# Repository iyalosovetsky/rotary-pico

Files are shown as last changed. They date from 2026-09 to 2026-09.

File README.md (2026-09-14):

*[Українська версія](README.uk.md)*

# rotary-pico

## 1. Description

Control firmware for a DIY turntable rig for a Creality Raptor-style 3D scanner, built on a **BTT SKR Pico** board (RP2040, MicroPython).

> See also [this grblHAL RP2040 fork](https://github.com/iyalosovetsky/RP2040_pico2w) — the same turntable/servo rig driven on top of grblHAL (M101 servo command, M102/M103/M104 table rotation) instead of standalone MicroPython.
>
> [Demo video](https://www.youtube.com/watch?v=oVeflQN5IRw) of the rig in action.

- **X axis** — rotates the table (continuous rotation, speed control), plus a one-shot relative rotation to a given angle.
- **Y/Z axes** — cyclic motion between a lower and upper limit, no physical endstops: `HOME` drives the axis until the TMC2209's StallGuard (sensorless homing) detects a genuine stall, then sets `MIN`/`MAX` to that position — a one-shot calibration, not something re-checked on every bounce. Also support a one-shot relative move to a given distance in millimeters, via a configurable lead screw pitch.
- **ST3215 servo (A)** — tilts the scanner head (cyclic motion between a minimum and maximum angle), plus a one-shot relative move to a given angle using the servo's own position feedback.

X/Y/Z track their current position (an open-loop step count, since none of them has a position sensor) and persist it so it survives a reboot; A doesn't need this since the servo always reports its own true position. `STATUS` shows every axis's position in physical units (mm/degrees).

All axes run concurrently and independently of each other (cooperative multitasking via `uasyncio`), controlled through G-code-like console commands.

The project was inspired by the [Creality Raptor Turntable](https://www.youtube.com/watch?v=kjL7HI78B2U&t=881s) video — `table_models/` contains the turntable models from the same author.

### Project files

| File / folder | Purpose |
|---|---|
| `tmc2209.py` | TMC2209 driver over UART (shared bus, MS1/MS2 addressing) |
| `st3215.py` | ST3215 servo driver (Feetech SMS/STS protocol) |
| `scanner_rig.py` | Orchestrator: async X/Y/Z/servo tasks + console command parser |
| `main.py` | Simple single-motor bench test (bring-up/diagnostics) |
| `test_y_motor.py` | Bench sweep: every microstep setting x three speeds, for characterizing real step rate vs. requested |
| `freecad/` | Own FreeCAD models (stepper motor, servo mount) |
| `table_models/` | Turntable models (STEP) from the inspiring video's author |

### Documentation

- [TMC2209_REGISTERS.md](TMC2209_REGISTERS.md) - every TMC2209 register this codebase uses, bit layouts, and a link to the datasheet
- [ST3215_REGISTERS.md](ST3215_REGISTERS.md) - every ST3215 register this codebase uses, units/scaling, and links to the datasheet
- [PINOUT.md](PINOUT.md) - BTT SKR Pico pin/header reference for this rig's wiring
- [TROUBLESHOOTING.md](TROUBLESHOOTING.md) - debugging log: bugs found, dead ends ruled out, current open issues

## 2. Command reference

Commands are sent one per line over the console (REPL). `MIN`/`MAX`/`SPEED`/`SGTHRS`/`LEAD`/`MICROSTEPS`/`CURRENT` with no value (e.g. `Y MIN`, not `Y MIN 0`) print that field's current value instead of setting it.

| Command | Description |
|---|---|
| `START [minutes]` | Start every axis at once (using whatever they're each already configured with), auto-stop after `minutes` (default 5) |
| `STOP` | Stop every axis immediately |
| `SLEEP` | Stop everything, disable the X/Y/Z drivers, release servo torque (see below) |
| `WAKE` | Undo `SLEEP` by hand (see below) |
| `X SPEED <steps_per_sec>` | Table rotation speed (sign sets direction, 0 = stopped) |
| `X START [CW\|CCW]` | Start table rotation - direction optional, defaults to CW (or last-used) |
| `X STOP` | Stop table rotation |
| `X MIN <deg>` | Default 0 - only used by `MOVE MIN`/`MID` (see below), not a limit on plain numeric `MOVE` |
| `X MAX <deg>` | Default 180 - only used by `MOVE MAX`/`MID` (see below), not a limit on plain numeric `MOVE` |
| `X MOVE <deg\|MIN\|MAX\|MID>` | A number is an unclamped signed relative rotation (multi-revolution moves like `720` are fine) - axis must be stopped first. `MIN`/`MAX`/`MID` go straight to that angle instead (see below) |
| `X ZERO` | Make the current position 0 (see below) |
| `X MICROSTEPS <n>` | Driver microstep resolution: one of 256/128/64/32/16/8/4/2/1 (see below) |
| `X CURRENT <mA>` | Run current for this axis's driver (hold current is auto-derived as half) |
| `X TMC` | TMC2209 driver health: faults, live current, microsteps, mode (see below) |
| `Y MIN <mm>` | Lower limit of carriage travel, in millimeters (via `LEAD`) - default 0 |
| `Y MAX <mm>` | Upper limit of carriage travel, in millimeters (via `LEAD`) - default 4 |
| `Y SPEED <steps_per_sec>` | Carriage speed |
| `Y SGTHRS <0-255>` | StallGuard sensorless-homing threshold (see below) - higher trips more easily |
| `Y HOME [DEC\|INC] [speed]` | One-shot calibration: home toward a StallGuard stall (see below) |
| `Y LEAD <mm>` | Lead screw pitch (mm per screw revolution) - used to convert `MOVE`'s millimeters to steps |
| `Y MOVE <mm\|MIN\|MAX\|MID>` | One-shot move: a signed relative distance in mm (clamped to `MIN`/`MAX`), or straight to `MIN`/`MAX`/the midpoint - axis must be stopped first |
| `Y ZERO` | Make the current position 0 (see below) |
| `Y MICROSTEPS <n>` | Driver microstep resolution: one of 256/128/64/32/16/8/4/2/1 (see below) |
| `Y CURRENT <mA>` | Run current for this axis's driver (hold current is auto-derived as half) |
| `Y TMC` | TMC2209 driver health: faults, live current, microsteps, mode (see below) |
| `Y START` | Start cyclic motion between `MIN` and `MAX` |
| `Y STOP` | Stop the carriage |
| `Z MIN <mm>` | Lower limit of Z travel, in millimeters (via `LEAD`) - default 0 |
| `Z MAX <mm>` | Upper limit of Z travel, in millimeters (via `LEAD`) - default 4 |
| `Z SPEED <steps_per_sec>` | Z axis speed |
| `Z SGTHRS <0-255>` | StallGuard sensorless-homing threshold (see below) - higher trips more easily |
| `Z HOME [DEC\|INC] [speed]` | One-shot calibration: home toward a StallGuard stall (see below) |
| `Z LEAD <mm>` | Lead screw pitch (mm per screw revolution) - used to convert `MOVE`'s millimeters to steps |
| `Z MOVE <mm\|MIN\|MAX\|MID>` | One-shot move: a signed relative distance in mm (clamped to `MIN`/`MAX`), or straight to `MIN`/`MAX`/the midpoint - axis must be stopped first |
| `Z ZERO` | Make the current position 0 (see below) |
| `Z MICROSTEPS <n>` | Driver microstep resolution: one of 256/128/64/32/16/8/4/2/1 (see below) |
| `Z CURRENT <mA>` | Run current for this axis's driver (hold current is auto-derived as half) |
| `Z TMC` | TMC2209 driver health: faults, live current, microsteps, mode (see below) |
| `Z START` | Start cyclic motion between `MIN` and `MAX` |
| `Z STOP` | Stop the Z axis |
| `A MIN <deg>` | Minimum scanner tilt angle (degrees) |
| `A MAX <deg>` | Maximum scanner tilt angle (degrees) |
| `A SPEED <raw_units>` | Servo speed (raw register units, tune empirically) |
| `A MOVE <deg\|MIN\|MAX\|MID>` | One-shot move: a signed relative angle in degrees (clamped to `MIN`/`MAX`), or straight to `MIN`/`MAX`/the midpoint - axis must be stopped first |
| `A TMC` | Servo health: voltage, temperature, load, current, error flags (see below) |
| `A START` | Start cyclic tilt between `MIN` and `MAX` |
| `A STOP` | Stop the servo |
| `STATUS` | Current position and config of all four axes (X/Y/Z in steps + degrees/mm, A read live from the servo) |
| `HELP` | Command help |

Example session:

```
Y HOME
Z HOME
X SPEED 200
X START
Y SPEED 400
Y START
Z SPEED 400
Z START
A MIN 30
A MAX 150
A SPEED 300
A START
STATUS
```

Or, for one-shot positioning instead of continuous cycling:

```
Y HOME
Y LEAD 4
Y MOVE 25.5
X MOVE 90
A MOVE -15
STATUS
```

Or straight to a limit instead of a relative distance:

```
Y MOVE MIN
Y MOVE MAX
Y MOVE MID
A MOVE MID
```

### Y/Z sensorless homing (StallGuard)

Y and Z have no physical endstop switches. Instead, `HOME` deliberately drives the axis toward one end (`DEC` = decreasing position, `INC` = increasing; Y defaults to `DEC`, Z to `INC`) while polling the TMC2209's StallGuard result (`SG_RESULT`) over UART - it drops as motor load rises, so driving into a real mechanical stop reads as a stall. Once that happens, `MIN` (for a `DEC` stall) or `MAX` (for an `INC` stall) is set to the position it stalled at.

This is a one-shot calibration - run `HOME` once before the first `START`, the way Klipper/Voron-style sensorless homing works. Ordinary bouncing afterward does **not** re-check StallGuard on every move: it runs the quieter stealthChop mode at full current, under which the StallGuard signal isn't reliable enough to act on. `HOME` switches to spreadCycle and a reduced current just for the homing move, then restores normal settings afterward.

`SGTHRS` has no universal default - it's specific to your motor, current, speed and mechanics, and must be tuned by hand:

1. Set a low `SGTHRS` (e.g. 1-3) and run `HOME`.
2. If it stops almost immediately (before reaching the real limit), lower `SGTHRS` further isn't the fix - it likely means the axis hasn't ramped up to a speed where StallGuard's reading is meaningful yet; check `HOME`'s speed argument.
3. If `HOME` fails with "StallGuard never tripped", raise `SGTHRS` until it reliably trips right at the real mechanical limit, not before.

### Zeroing the origin (ZERO)

`X`/`Y`/`Z ZERO` does the same zeroing `HOME` does (current position becomes 0, `MIN`/`MAX` shift by the same offset so they keep meaning the same real distance from the new origin) but instantly, wherever the axis currently is - no motion, no StallGuard involved. Use it to redefine the origin by hand instead of (or in addition to) a StallGuard-based `HOME`. X has no `HOME` at all (continuous rotation, nothing to stall against), so `ZERO` is its only way to get a zero reference.

### Physical-unit positioning (LEAD, MOVE)

`Y`/`Z MOVE` takes a distance in millimeters, converted to motor steps via that axis's `LEAD` (millimeters per lead-screw revolution - depends on your actual hardware, so it's configurable, default 4mm) and that axis's own `MICROSTEPS` setting (see below). `X MOVE` takes an angle in degrees instead, since X turns the turntable directly rather than driving a screw. `A MOVE` also takes degrees, but unlike the open-loop stepper axes, it reads the servo's own absolute position feedback and issues a single absolute goal instead of counting steps.

All four `MOVE` commands are one-shot and require the axis not already running/bouncing. Given a number, `MOVE` is a signed relative move from the current position - clamped to `MIN`/`MAX` for Y/Z/A (`MIN`/`MAX` are millimeters for Y/Z, same as `MOVE`, and degrees for A), but **not** for X: X is continuous rotation, so a plain numeric `X MOVE` is deliberately unbounded, letting multi-revolution moves like `X MOVE 720` (two full turns) through untouched. Given `MIN`, `MAX`, or `MID` instead of a number, all four axes go straight to that limit (or the midpoint between them) from wherever they currently are - an absolute move, not a relative one; this is the only thing X's own `MIN`/`MAX` (in degrees, default 0/180 so `MID` = 90) are used for.

### Microstepping and current (MICROSTEPS, CURRENT)

Each of X/Y/Z has its own configurable `MICROSTEPS` (one of 256/128/64/32/16/8/4/2/1, default 16) and `CURRENT` (run current in mA - hold current is always auto-derived as half of it), persisted independently per axis. Changing `MICROSTEPS` rescales `pos`/`MIN`/`MAX` by the resolution ratio (e.g. 16→32 doubles them): a single step means a different real distance at a different resolution, so without rescaling, an existing `HOME` calibration would silently stop matching reality instead of just needing conversion. `CURRENT` is independent of `HOME_CURRENT_MA` in `scanner_rig.py`, which only applies transiently during the `HOME` move itself and is restored to this per-axis `CURRENT` afterward.

### Driver/servo health (TMC)

`X`/`Y`/`Z TMC` decodes that TMC2209's GSTAT/DRV_STATUS registers into a one-line health summary: `OK`, or `ERROR(...)` listing any of `RESET`/`DRV_ERR`/`UV_CP` (GSTAT) or `OTPW`/`OT`/`S2GA`/`S2GB`/`S2VSA`/`S2VSB`/`OLA`/`OLB` (DRV_STATUS) that are set, plus the driver's live actual current in mA, its microsteps (read back from the chip, not assumed), mode (stealthChop/spreadCycle), standstill, and - for Y/Z - `sgthrs=N(cfg)` (SGTHRS can't be read back from this chip, so this echoes the last value configured in software, not a hardware readback). `RESET` is expected once right after power-up; GSTAT is cleared on each read so it doesn't keep reporting an old event. See [TMC2209_REGISTERS.md](TMC2209_REGISTERS.md) for the full register/bit reference.

`A TMC` reads the ST3215's own feedback registers (voltage, temperature, load, current) plus the status/error byte every reply carries, decoded the same way: `OK`, or `ERROR(...)` listing any of `VOLTAGE`/`ANGLE`/`OVERHEAT`/`OVERELE`/`OVERLOAD`. `load` is a raw signed magnitude, not a calibrated percentage - see [ST3215_REGISTERS.md](ST3215_REGISTERS.md).

Both are useful for catching a motor/servo that's silently drawing less current or running hotter than expected, without pulling a multimeter.

### Position tracking

X/Y/Z have no position sensor - their `pos` is just an open-loop step count. It's checkpointed to `rig_config.json` every 10 minutes while it's changing, and immediately whenever an axis is stopped or the rig goes to `SLEEP`, so a reboot doesn't lose track of where the mechanism physically is. That interval is long on purpose: writing to flash blocks the whole program for 50-100+ms (measured on real hardware) - MicroPython's flash writes are synchronous, so nothing else (including the step timing of whatever's moving) can run until it returns. At a much shorter interval this was a felt stutter during continuous motion; `STOP`/`SLEEP` cover the common "about to sit idle" case immediately instead of waiting on the timer. A doesn't need any of this: the ST3215 servo always reports its own true absolute angle over UART, so `STATUS` just reads it live.

### Idle power-down (SLEEP, WAKE)

`SLEEP` stops every axis, then disables the X/Y/Z TMC2209 drivers outright (their `EN` pin - no holding current at all, quieter and cooler than just standing still with the normal hold current) and releases the ST3215's torque. It happens either by typing `SLEEP` yourself, or automatically after 20 minutes with no console input at all and nothing running (checked periodically - it never fires while any axis is actually moving, no matter how stale the last-input time is).

Any `START`, `MOVE`, or `HOME` command, for any axis, wakes everything back up first, the same as typing `WAKE` directly. Commands that don't cause movement (`SPEED`, `MIN`/`MAX`, `TMC`, `STATUS`, etc.) leave it asleep and still work fine - UART communication with the TMC2209s doesn't depend on the `EN` pin.

Because a torque-less servo can sag under the weight of whatever it's holding, `WAKE` compares the servo's angle against what it was right before `SLEEP` and, if it moved by more than a degree, commands it back to where it was. X/Y/Z don't get this treatment: nothing in this rig loads them with enough gravity to drift while unpowered, and even if it did, there's no sensor on those axes to detect it - that's the whole reason `SLEEP` disables them rather than tracking drift the way it does for the servo.

## 3. Component list

| Component | Photo | Description | Docs |
|---|---|---|---|
| **BTT SKR Pico V1.0** |  | RP2040 control board, 2MB flash, 4 onboard TMC2209 drivers (UART, shared bus with MS1/MS2 addressing), USB-C | [GitHub: bigtreetech/SKR-Pico](https://github.com/bigtreetech/SKR-Pico) |
| **ST3215** |  | Serial bus servo (Feetech SMS/STS), 360° magnetic encoder, UART control (single-wire), up to 30 kg·cm torque | [Waveshare Wiki: ST3215 Servo](https://www.waveshare.com/wiki/ST3215_Servo) |
| **NEMA17 34mm** |  | Stepper motor, short (34mm) version — lower torque, smaller size/weight, driven by TMC2209 | — |
| **Waveshare Bus Servo Adapter (A)** |  | UART (TX/RX) → single-wire half-duplex bus adapter for Feetech/Waveshare servos, powers the servo | [Waveshare Wiki: Bus Servo Adapter (A)](https://www.waveshare.com/wiki/Bus_Servo_Adapter_(A)) |

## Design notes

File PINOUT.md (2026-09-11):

*[Українська версія](PINOUT.uk.md)*

# BTT SKR Pico V1.0 — Pinout

GPIO numbering and connector assignments cross-checked against the official [bigtreetech/SKR-Pico](https://github.com/bigtreetech/SKR-Pico) diagram (`Klipper/Images/pinout.png`). The "In this project" column shows how each pin is actually used here (`tmc2209.py`, `st3215.py`, `scanner_rig.py`).

## Stepper motors

| Axis | EN | STEP | DIR | UART address | In this project |
|---|---|---|---|---|---|
| X | IO12 | IO11 | IO10 | 0 | Table — continuous rotation |
| Y | IO7 | IO6 | IO5 | 2 | Scanner carriage — bounces between MIN/MAX |
| Z | IO2 | IO19 | IO28 | 1 | unused |
| E0 | IO15 | IO14 | IO13 | 3 | unused |

**Motor UART (shared bus, all 4 drivers):** TX = IO8, RX = IO9

## Endstops

| Connector | Signal | In this project |
|---|---|---|
| X-STOP | IO4 | free (open-loop motion, no homing) |
| Y-STOP | IO3 | free |
| Z-STOP | IO25 | free |
| E0-STOP | IO16 | free |

## Thermistors / heaters

| Connector | Signal | In this project |
|---|---|---|
| TH0 | IO27 | unused |
| THB | IO26 | unused |
| HE (hotend heater) | IO23 | unused |
| HB (bed heater) | IO21 | unused |

## Fans

| Connector | Signal | In this project |
|---|---|---|
| FAN1 | IO17 | free |
| FAN2 | IO18 | free |
| FAN3 | IO20 | free |

## Other

| Connector | Signal(s) | In this project |
|---|---|---|
| RGB (Neopixel) | IO24 | unused |
| PROBE | IO22 | free (BLTouch-style signal) |
| SERVOS | IO29 | free (1 PWM pin — **not suitable** for ST3215 UART, which needs 2 lines) |
| **Laser** | **IO0 (TX), IO1 (RX)**, GND, 5V | **ST3215 servo bus** via the Waveshare Bus Servo Adapter (A) — these are the exact pins used in `scanner_rig.py` (`ServoBus(uart_id=0, tx=0, rx=1)`). ⚠️ The TX/RX silkscreen labels on this particular adapter board are swapped (mislabeled) — go by what actually works, not the printed labels. |
| Power | GND, 12/24V | board/driver power input |
| USB | USB_DP (D+), USB_DM (D-), Type-C | console/REPL, logic power |

## Free pins for expansion

Z (`step=IO19 dir=IO28 en=IO2`, addr=1) and E0 (`step=IO14 dir=IO13 en=IO15`, addr=3) are fully free motor channels on the same TMC2209 UART bus, in case another axis is needed (e.g. a separate focus mechanism). Endstops, thermistors, heaters, FAN1-3, RGB, and PROBE are also free.

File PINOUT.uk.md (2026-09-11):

*[English version](PINOUT.md)*

# BTT SKR Pico V1.0 — розпіновка

GPIO-нумерація та призначення конекторів звірені з офіційною схемою [bigtreetech/SKR-Pico](https://github.com/bigtreetech/SKR-Pico) (`Klipper/Images/pinout.png`). Колонка "У проєкті" — як пін використовується в цьому репозиторії (`tmc2209.py`, `st3215.py`, `scanner_rig.py`).

## Крокові двигуни

| Вісь | EN | STEP | DIR | UART address | У проєкті |
|---|---|---|---|---|---|
| X | IO12 | IO11 | IO10 | 0 | Стіл — безкінечне обертання |
| Y | IO7 | IO6 | IO5 | 2 | Каретка сканера — гойдалка MIN↔MAX |
| Z | IO2 | IO19 | IO28 | 1 | не використовується |
| E0 | IO15 | IO14 | IO13 | 3 | не використовується |

**Motor UART (спільна шина, всі 4 драйвери):** TX = IO8, RX = IO9

## Кінцевики (endstops)

| Конектор | Сигнал | У проєкті |
|---|---|---|
| X-STOP | IO4 | вільний (рух відкритий, без хомінгу) |
| Y-STOP | IO3 | вільний |
| Z-STOP | IO25 | вільний |
| E0-STOP | IO16 | вільний |

## Термістори / нагрівачі

| Конектор | Сигнал | У проєкті |
|---|---|---|
| TH0 | IO27 | не використовується |
| THB | IO26 | не використовується |
| HE (нагрівач хотенда) | IO23 | не використовується |
| HB (нагрівач стола) | IO21 | не використовується |

## Вентилятори

| Конектор | Сигнал | У проєкті |
|---|---|---|
| FAN1 | IO17 | вільний |
| FAN2 | IO18 | вільний |
| FAN3 | IO20 | вільний |

## Інше

| Конектор | Сигнал(и) | У проєкті |
|---|---|---|
| RGB (Neopixel) | IO24 | не використовується |
| PROBE | IO22 | вільний (сигнал BLTouch-типу) |
| SERVOS | IO29 | вільний (1 PWM-пін, **не підходить** під UART ST3215 — потрібні 2 лінії) |
| **Laser** | **IO0 (TX), IO1 (RX)**, GND, 5V | **шина сервопривода ST3215** через Waveshare Bus Servo Adapter (A) — саме ці піни підставлені в `scanner_rig.py` (`ServoBus(uart_id=0, tx=0, rx=1)`). ⚠️ Підписи TX/RX на шовкографії саме цього адаптера переплутані (виробник помилився) — орієнтуйтесь на те, що реально працює, а не на надруковані підписи. |
| Power | GND, 12/24V | силове живлення плати/драйверів |
| USB | USB_DP (D+), USB_DM (D-), Type-C | консоль/REPL, живлення логіки |

## Вільні піни для розширення

Z (`step=IO19 dir=IO28 en=IO2`, addr=1) і E0 (`step=IO14 dir=IO13 en=IO15`, addr=3) — повністю вільні мотор-канали на тій самій UART-шині TMC2209, якщо знадобиться ще одна вісь (наприклад, окрема фокусировка). Кінцевики, термістори, нагрівачі, FAN1-3, RGB, PROBE — теж вільні.

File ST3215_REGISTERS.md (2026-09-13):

*[Українська версія](ST3215_REGISTERS.uk.md)*

# ST3215 register reference

Every register `st3215.py` actually reads or writes, why, and what units/scaling apply. This is not a full transcription of the datasheet - only what this codebase touches. Addresses were verified against the official Feetech/Waveshare SDK vendored in this repo (`scservo_sdk/sms_sts.py`, from [ftservo/FTServo_Python](https://github.com/ftservo/FTServo_Python)) and the [`parallax/scservo`](https://github.com/parallaxinc/scservo) reference. For anything not covered here:

- **[Feetech STS3215 official product specification (PDF)](https://www.feetechrc.com/Data/feetechrc/upload/file/20200611/6372749961523760249976542.pdf)** (mirror: [seeedstudio.com](https://files.seeedstudio.com/products/Feetech/108090023_STS3215-C001_Datasheet.pdf))
- **[Waveshare Wiki: ST3215 Servo](https://www.waveshare.com/wiki/ST3215_Servo)**

## Packet protocol (how `st3215.py` talks to the servo)

Feetech SMS/STS protocol, packet-based, checksum instead of CRC:

- Packet: `0xFF 0xFF | id | length | instruction | params... | checksum`
- `checksum = (~(id + length + instruction + sum(params))) & 0xFF`
- Instructions used here: `PING (1)`, `READ (2)`, `WRITE (3)`
- Unlike the TMC2209 bus (a bare resistor tying TX into RX, so every byte echoes and must be drained), the Waveshare Bus Servo Adapter (A) is a real transceiver - TX/RX stay electrically separate, so there is **no self-echo** to drain on this bus. See `st3215.py`'s module docstring and [TROUBLESHOOTING.md](TROUBLESHOOTING.md) for the bug this distinction caused when the TMC2209 bus's echo-drain pattern was copied here by mistake.
- Every reply carries a status/error byte (`reply[4]`), decoded by `get_error_text()` into the `ERRBIT_*` flags below - this is what `diag_summary()`'s `ERROR(...)` list comes from.

## Register table

| Addr | Register | Bytes | Access | Used for |
|---|---|---|---|---|
| 3 | MODEL_L (+4: MODEL_H) | 2 | R | Model number (`ping_verbose()`) |
| 9 | MIN_ANGLE_LIMIT_L (+10: _H) | 2 | R/W (EPROM) | Declared, not currently used by this codebase |
| 11 | MAX_ANGLE_LIMIT_L (+12: _H) | 2 | R/W (EPROM) | Declared, not currently used by this codebase |
| 33 | MODE | 1 | R/W (EPROM) | Declared, not currently used by this codebase |
| 40 | TORQUE_ENABLE | 1 | R/W | Enable/disable torque (`torque_enable()`) |
| 41 | ACC | 1 | R/W | Acceleration, raw units 0-254 (`set_acceleration()`) - exact accel-per-unit isn't documented consistently, calibrate by eye |
| 42 | GOAL_POSITION_L (+43: _H) | 2 | R/W | Target position (`set_goal()`/`set_goal_deg()`) |
| 44 | GOAL_TIME_L (+45: _H) | 2 | R/W | Move duration; left at 0 by this driver so the servo uses GOAL_SPEED instead of a fixed time |
| 46 | GOAL_SPEED_L (+47: _H) | 2 | R/W | Move speed, raw servo-internal units (~0-3400 typical) |
| 56 | PRESENT_POSITION_L (+57: _H) | 2 | R | Live absolute position (`read_position()`/`read_position_deg()`) |
| 60 | PRESENT_LOAD_L (+61: _H) | 2 | R | Live load: bits 0-9 magnitude, bit 10 direction (`read_load()`) - see note below |
| 62 | PRESENT_VOLTAGE | 1 | R | Live supply voltage, raw × 0.1 = volts (`read_voltage()`) |
| 63 | PRESENT_TEMPERATURE | 1 | R | Live temperature, raw value is already °C (`read_temperature()`) |
| 66 | MOVING | 1 | R | Whether the servo is currently moving (`is_moving()`) |
| 69 | PRESENT_CURRENT_L (+70: _H) | 2 | R | Live current draw, raw × 6.5 = mA (`read_current_ma()`) |

**EPROM** registers persist across power cycles but require the EPROM to be unlocked (`LockEprom`/`unLockEprom` in the official SDK - not implemented in `st3215.py`, since this driver never writes them).

### PRESENT_LOAD: magnitude is not independently confirmed as a percentage

Some community register references describe PRESENT_LOAD as 0-1000 representing 0-100.0% of maximum torque, but this wasn't found stated plainly enough in the official spec to rely on. `read_load()` therefore returns the raw signed magnitude (0-1023, negative when the direction bit is set) rather than asserting a percentage scale it can't back up.

## Status/error byte (`ERRBIT_*` in `st3215.py`)

Returned as byte index 4 of every reply packet - not a separately-addressed register, but the closest equivalent to the TMC2209's GSTAT/DRV_STATUS fault flags, and what `diag_summary()`'s `ERROR(...)` list is built from:

| Bit | Constant | Meaning |
|---|---|---|
| 0 | `ERRBIT_VOLTAGE` | Input voltage error |
| 1 | `ERRBIT_ANGLE` | Angle sensor error |
| 2 | `ERRBIT_OVERHEAT` | Overheat error |
| 3 | `ERRBIT_OVERELE` | Over-electrical-current (OverEle) error |
| 5 | `ERRBIT_OVERLOAD` | Overload error |

These match the official Waveshare/Feetech `scservo_sdk` (`protocol_packet_handler.py`)'s error-bit constants, which is why `get_result_text()`/`get_error_text()` read the same as the vendored `STServo_Python` demo scripts' own output.

## Position/angle conversion

`UNITS_PER_REV = 4096` (12-bit position sensor, magnetic encoder, one full 360° turn):

```
deg_to_units(deg) = round(deg / 360 * 4096), clamped to 0..4095
units_to_deg(units) = units * 360 / 4096
```

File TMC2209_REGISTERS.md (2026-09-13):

*[Українська версія](TMC2209_REGISTERS.uk.md)*

# TMC2209 register reference

Every register `tmc2209.py` actually reads or writes, why, and what the relevant bits mean. This is not a full transcription of the datasheet - only what this codebase touches. For anything not covered here, see the official datasheet:

**[TMC2209 Datasheet, Rev. 1.09](https://www.analog.com/media/en/technical-documentation/data-sheets/tmc2209_datasheet_rev1.09.pdf)** (Analog Devices / Trinamic Motion Control). Section numbers below (e.g. "5.5.3") refer to this document.

## Datagram protocol (how `tmc2209.py` talks to the chip)

All 4 on-board drivers share one UART bus, distinguished by a node address (0-3) set via each chip's MS1/MS2 strapping. Datasheet section 5, "UART Single Wire Interface":

- **Write** (8 bytes): `sync(0x05) | addr | reg|0x80 | data[3] | data[2] | data[1] | data[0] | CRC8`
- **Read request** (4 bytes): `sync(0x05) | addr | reg&0x7F | CRC8`, chip replies with an 8-byte datagram: `sync(0x05) | 0xFF(master addr) | reg | data[3..0] | CRC8`
- CRC8 uses the polynomial 0x07 (bit-reversed), implemented in `_crc8()`.
- TX is wired into RX through a resistor on this board (BTT SKR Pico), so **every transmitted byte echoes back** and must be drained before reading a real reply - see `TMC2209Bus._flush_rx()`/`_read_exact()`.

## Register table

| Addr | Register | Access | Used for |
|---|---|---|---|
| 0x00 | GCONF | R+W | UART mode setup (`pdn_disable`, `mstep_reg_select`), stealthChop/spreadCycle select |
| 0x01 | GSTAT | R+WC | Driver health: reset/overtemp-or-short/undervoltage flags - `diag_summary()` |
| 0x06 | IOIN | R | Chip version check (`check_connection()`) |
| 0x10 | IHOLD_IRUN | **W (write-only)** | Run/hold current (`set_current()`) |
| 0x13 | TPWMTHRS | W | Declared, not currently used by this codebase |
| 0x14 | TCOOLTHRS | **W (write-only)** | StallGuard/CoolStep minimum-speed threshold (`enable_stallguard()`) |
| 0x40 | SGTHRS | **W (write-only)** | StallGuard stall threshold (`enable_stallguard()`) |
| 0x41 | SG_RESULT | R | Live StallGuard load reading, polled during `HOME` (`read_stallguard_result()`) |
| 0x6C | CHOPCONF | R+W | Microstep resolution / MRES field (`set_microsteps()`, `read_microsteps()`) |
| 0x6F | DRV_STATUS | R | Fault flags, live current scale, mode, standstill - `diag_summary()` |
| 0x70 | PWMCONF | R+W | stealthChop `pwm_autoscale`/`pwm_autograd` bits (`enable_uart_mode()`) |

**R+WC** = read, write-clear: writing `1` to a bit clears it (used for GSTAT - see `clear_gstat()`).

### Write-only registers: don't try to verify them by reading back

IHOLD_IRUN, TCOOLTHRS, and SGTHRS are marked **W** in the datasheet's register access table - the chip does not return their contents on a read, regardless of whether the write succeeded. Reading any of them back always returns `0x00000000`. This tripped up an earlier debugging session in this project (documented in [TROUBLESHOOTING.md](TROUBLESHOOTING.md)): a `0x00000000` readback on these three was mistaken for a failed write, when the writes had actually succeeded all along. Only GCONF/CHOPCONF/PWMCONF (all R+W) are meaningful to read back for verification.

This is also why `X/Y/Z TMC`'s `sgthrs=N(cfg)` in `scanner_rig.py` is labeled `(cfg)`: it's the value the software last configured the register to, not something read from the chip.

## GCONF (0x00) bits used here

| Bit | Name (as used in this code) | Meaning |
|---|---|---|
| 2 | `en_spreadcycle` (`spreadcycle` param to `enable_uart_mode()`) | 0 = stealthChop (quiet, used for normal bouncing), 1 = spreadCycle (used only during `HOME`, where StallGuard needs a clean signal) |
| 6 | `pdn_disable` | Must be set for UART operation (frees the PDN_UART pin from its pin-down/analog-select role) |
| 7 | `mstep_reg_select` | Must be set so microstep resolution comes from CHOPCONF's MRES field (register control) instead of the MS1/MS2 pins |

## GSTAT (0x01) bits - datasheet "general configuration registers" table

| Bit | Name | Meaning |
|---|---|---|
| 0 | `reset` | IC has been reset since the last GSTAT read - expected once right after power-up |
| 1 | `drv_err` | Driver shut down due to overtemperature or short-circuit (see DRV_STATUS for which) |
| 2 | `uv_cp` | Undervoltage on the charge pump - driver disabled while this is set |

## DRV_STATUS (0x6F) bits - datasheet section 5.5.3

| Bit | Name | Meaning |
|---|---|---|
| 0 | `otpw` | Overtemperature pre-warning |
| 1 | `ot` | Overtemperature shutdown |
| 2 | `s2ga` | Short to ground, phase A |
| 3 | `s2gb` | Short to ground, phase B |
| 4 | `s2vsa` | Low-side short, phase A |
| 5 | `s2vsb` | Low-side short, phase B |
| 6 | `ola` | Open load, phase A (informative only - the datasheet notes false positives during fast motion/standstill; check during slow motion) |
| 7 | `olb` | Open load, phase B (same caveat) |
| 8-11 | `t120`/`t143`/`t150`/`t157` | Temperature threshold comparators - not decoded by `diag_summary()` (otpw/ot cover the practically useful cases) |
| 16-20 | `cs_actual` | Live current-scale (0-31) actually applied - converted to mA by `cs_to_ma()`, the inverse of `set_current()`'s formula. This is `IHOLD`'s scale while `standstill=1`, `IRUN`'s while moving - not simply "whatever `set_current()` was last called with" |
| 30 | `stealth` | 1 = stealthChop active, 0 = spreadCycle |
| 31 | `stst` | Standstill: motor has been stopped for 2^20 clocks |

## IHOLD_IRUN (0x10) layout

| Bits | Field | Notes |
|---|---|---|
| 4:0 | `IHOLD` | Hold current scale (0-31), applied at standstill |
| 12:8 | `IRUN` | Run current scale (0-31), applied while moving |
| 19:16 | `IHOLDDELAY` | Delay (in units of ~2^18 clocks) before ramping down from IRUN to IHOLD after motion stops |

Current-scale (CS) formula used by `set_current()`/`cs_to_ma()` (`_ma_to_cs`/`cs_to_ma` in `tmc2209.py`), the standard Trinamic formula:

```
CS = round(32 * sqrt(2) * I_rms_amps * (Rsense + 0.02) / Vfs - 1)   # clamped to 0-31
Vfs = 0.180 if vsense else 0.325
```

`Rsense`/`vsense` are constructor args on `TMC2209` (default `rsense=0.11, vsense=False`, matching the BTT SKR Pico's onboard drivers) - not hardcoded into the formula, in case a different board/driver current-sense config is ever used.

## CHOPCONF (0x6C): MRES field (bits 27:24)

`set_microsteps()`/`read_microsteps()` only touch this field, preserving every other CHOPCONF bit (read-modify-write):

| MRES | Microsteps |
|---|---|
| 0 | 256 |
| 1 | 128 |
| 2 | 64 |
| 3 | 32 |
| 4 | 16 (this rig's default - see `MICROSTEPS` in `scanner_rig.py`) |
| 5 | 8 |
| 6 | 4 |
| 7 | 2 |
| 8 | 1 (full step) |

## PWMCONF (0x70) bits used here

| Bit | Name | Meaning |
|---|---|---|
| 18 | `pwm_autoscale` | stealthChop's current-regulation loop adapts PWM amplitude to the actual motor/load, instead of running open-loop off reset defaults |
| 19 | `pwm_autograd` | Automatic tuning of the PWM gradient, used together with `pwm_autoscale` |

Both are set by `enable_uart_mode()` via read-modify-write, leaving the factory `pwm_freq`/`pwm_grad`/`pwm_ofs` defaults untouched.

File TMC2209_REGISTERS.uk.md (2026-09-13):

*[English version](TMC2209_REGISTERS.md)*

# Довідник по регістрах TMC2209

Кожен регістр, який `tmc2209.py` реально читає чи записує, навіщо, і що означають відповідні біти. Це не повний переклад даташиту — лише те, чого торкається цей код. Для всього іншого дивіться офіційний даташит:

**[TMC2209 Datasheet, Rev. 1.09](https://www.analog.com/media/en/technical-documentation/data-sheets/tmc2209_datasheet_rev1.09.pdf)** (Analog Devices / Trinamic Motion Control). Номери розділів нижче (наприклад, "5.5.3") посилаються саме на цей документ.

## Протокол датаграм (як `tmc2209.py` спілкується з чіпом)

Усі 4 вбудовані драйвери діляться однією шиною UART, розрізняються за адресою вузла (0-3), яка задається strapping'ом MS1/MS2 кожного чіпа. Розділ 5 даташиту, "UART Single Wire Interface":

- **Запис** (8 байт): `sync(0x05) | addr | reg|0x80 | data[3] | data[2] | data[1] | data[0] | CRC8`
- **Запит читання** (4 байти): `sync(0x05) | addr | reg&0x7F | CRC8`, чіп відповідає 8-байтною датаграмою: `sync(0x05) | 0xFF(адреса майстра) | reg | data[3..0] | CRC8`
- CRC8 використовує поліном 0x07 (з реверсом бітів), реалізовано в `_crc8()`.
- На цій платі (BTT SKR Pico) TX з'єднаний з RX через резистор, тож **кожен відправлений байт повертається як ехо** і має бути вичитаний перед реальною відповіддю — див. `TMC2209Bus._flush_rx()`/`_read_exact()`.

## Таблиця регістрів

| Адр | Регістр | Доступ | Використання |
|---|---|---|---|
| 0x00 | GCONF | R+W | Налаштування режиму UART (`pdn_disable`, `mstep_reg_select`), вибір stealthChop/spreadCycle |
| 0x01 | GSTAT | R+WC | Стан драйвера: прапори reset/перегрів-або-КЗ/недостатня напруга — `diag_summary()` |
| 0x06 | IOIN | R | Перевірка версії чіпа (`check_connection()`) |
| 0x10 | IHOLD_IRUN | **W (тільки запис)** | Робочий/утримуючий струм (`set_current()`) |
| 0x13 | TPWMTHRS | W | Оголошено, але наразі не використовується цим кодом |
| 0x14 | TCOOLTHRS | **W (тільки запис)** | Мінімальний поріг швидкості StallGuard/CoolStep (`enable_stallguard()`) |
| 0x40 | SGTHRS | **W (тільки запис)** | Поріг застою StallGuard (`enable_stallguard()`) |
| 0x41 | SG_RESULT | R | Живий показник навантаження StallGuard, опитується під час `HOME` (`read_stallguard_result()`) |
| 0x6C | CHOPCONF | R+W | Роздільність мікрокроку / поле MRES (`set_microsteps()`, `read_microsteps()`) |
| 0x6F | DRV_STATUS | R | Прапори несправностей, жива шкала струму, режим, standstill — `diag_summary()` |
| 0x70 | PWMCONF | R+W | Біти `pwm_autoscale`/`pwm_autograd` для stealthChop (`enable_uart_mode()`) |

**R+WC** = читання, запис-очищення: запис `1` в біт очищує його (використовується для GSTAT — див. `clear_gstat()`).

### Регістри "тільки запис": не намагайтесь перевіряти їх читанням

IHOLD_IRUN, TCOOLTHRS та SGTHRS позначені **W** в таблиці доступу до регістрів даташиту — чіп не повертає їхній вміст при читанні, незалежно від того, чи запис пройшов успішно. Читання будь-якого з них завжди повертає `0x00000000`. Це збило з пантелику попередню сесію діагностики в цьому проєкті (задокументовано в [TROUBLESHOOTING.md](TROUBLESHOOTING.md)): читання `0x00000000` для цих трьох було помилково прийняте за невдалий запис, хоча записи насправді весь час проходили успішно. Лише GCONF/CHOPCONF/PWMCONF (усі R+W) мають сенс для перевірки читанням.

Саме тому `sgthrs=N(cfg)` в `X/Y/Z TMC` в `scanner_rig.py` позначено `(cfg)`: це те значення, яке програма останнім записала в регістр, а не те, що зчитано з чіпа.

## Біти GCONF (0x00), що використовуються тут

| Біт | Назва (як у цьому коді) | Значення |
|---|---|---|
| 2 | `en_spreadcycle` (параметр `spreadcycle` у `enable_uart_mode()`) | 0 = stealthChop (тихий, для звичайного циклічного руху), 1 = spreadCycle (лише під час `HOME`, де StallGuard потребує чистого сигналу) |
| 6 | `pdn_disable` | Має бути встановлений для роботи UART (звільняє пін PDN_UART від ролі pin-down/аналогового вибору) |
| 7 | `mstep_reg_select` | Має бути встановлений, щоб роздільність мікрокроку бралась з поля MRES регістра CHOPCONF (керування регістром), а не з пінів MS1/MS2 |

## Біти GSTAT (0x01) — таблиця "general configuration registers" даташиту

| Біт | Назва | Значення |
|---|---|---|
| 0 | `reset` | Чіп був скинутий з моменту останнього читання GSTAT — очікувано одразу після подачі живлення |
| 1 | `drv_err` | Драйвер вимкнено через перегрів або коротке замикання (див. DRV_STATUS, яке саме) |
| 2 | `uv_cp` | Недостатня напруга на charge pump — драйвер вимкнено, поки цей біт встановлено |

## Біти DRV_STATUS (0x6F) — розділ 5.5.3 даташиту

| Біт | Назва | Значення |
|---|---|---|
| 0 | `otpw` | Попередження про перегрів |
| 1 | `ot` | Вимкнення через перегрів |
| 2 | `s2ga` | Коротке замикання на землю, фаза A |
| 3 | `s2gb` | Коротке замикання на землю, фаза B |
| 4 | `s2vsa` | Коротке замикання на низькій стороні, фаза A |
| 5 | `s2vsb` | Коротке замикання на низькій стороні, фаза B |
| 6 | `ola` | Обрив навантаження, фаза A (лише інформативно — даташит зазначає хибні спрацювання під час швидкого руху/спокою; перевіряйте на повільному русі) |
| 7 | `olb` | Обрив навантаження, фаза B (те саме застереження) |
| 8-11 | `t120`/`t143`/`t150`/`t157` | Компаратори температурних порогів — не декодуються `diag_summary()` (otpw/ot покривають практично корисні випадки) |
| 16-20 | `cs_actual` | Жива шкала струму (0-31), яка реально застосовується — конвертується в мА через `cs_to_ma()`, обернену до формули `set_current()`. Це шкала `IHOLD`, поки `standstill=1`, і `IRUN` — під час руху, а не просто "те, з чим останнього разу викликали `set_current()`" |
| 30 | `stealth` | 1 = активний stealthChop, 0 = spreadCycle |
| 31 | `stst` | Standstill: мотор нерухомий вже 2^20 тактів |

## Розкладка IHOLD_IRUN (0x10)

| Біти | Поле | Примітки |
|---|---|---|
| 4:0 | `IHOLD` | Шкала утримуючого струму (0-31), застосовується в стані спокою |
| 12:8 | `IRUN` | Шкала робочого струму (0-31), застосовується під час руху |
| 19:16 | `IHOLDDELAY` | Затримка (в одиницях ~2^18 тактів) перед переходом з IRUN на IHOLD після зупинки руху |

Формула шкали струму (CS), яку використовують `set_current()`/`cs_to_ma()` (`_ma_to_cs`/`cs_to_ma` в `tmc2209.py`) — стандартна формула Trinamic:

```
CS = round(32 * sqrt(2) * I_rms_amps * (Rsense + 0.02) / Vfs - 1)   # обмежено 0-31
Vfs = 0.180 якщо vsense, інакше 0.325
```

`Rsense`/`vsense` — аргументи конструктора `TMC2209` (за замовчуванням `rsense=0.11, vsense=False`, що відповідає вбудованим драйверам BTT SKR Pico) — не захардкоджені у формулу, на випадок якщо колись знадобиться інша плата/конфігурація токовимірювального резистора.

## CHOPCONF (0x6C): поле MRES (біти 27:24)

`set_microsteps()`/`read_microsteps()` торкаються лише цього поля, зберігаючи всі інші біти CHOPCONF (read-modify-write):

| MRES | Мікрокроків |
|---|---|
| 0 | 256 |
| 1 | 128 |
| 2 | 64 |
| 3 | 32 |
| 4 | 16 (дефолт цього рига — див. `MICROSTEPS` в `scanner_rig.py`) |
| 5 | 8 |
| 6 | 4 |
| 7 | 2 |
| 8 | 1 (повний крок) |

## Біти PWMCONF (0x70), що використовуються тут

| Біт | Назва | Значення |
|---|---|---|
| 18 | `pwm_autoscale` | Контур регулювання струму stealthChop підлаштовує амплітуду ШІМ під реальний мотор/навантаження, замість роботи "розімкнено" на заводських значеннях |
| 19 | `pwm_autograd` | Автоматичне налаштування градієнта ШІМ, використовується разом з `pwm_autoscale` |

Обидва встановлюються `enable_uart_mode()` через read-modify-write, залишаючи заводські `pwm_freq`/`pwm_grad`/`pwm_ofs` незмінними.

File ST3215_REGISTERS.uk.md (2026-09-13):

*[English version](ST3215_REGISTERS.md)*

# Довідник по регістрах ST3215

Кожен регістр, який `st3215.py` реально читає чи записує, навіщо, і які одиниці/масштаб застосовуються. Це не повний переклад даташиту — лише те, чого торкається цей код. Адреси звірені з офіційним SDK Feetech/Waveshare, вендореним у цьому репозиторії (`scservo_sdk/sms_sts.py`, з [ftservo/FTServo_Python](https://github.com/ftservo/FTServo_Python)), та еталоном [`parallax/scservo`](https://github.com/parallaxinc/scservo). Для всього іншого:

- **[Офіційна специфікація Feetech STS3215 (PDF)](https://www.feetechrc.com/Data/feetechrc/upload/file/20200611/6372749961523760249976542.pdf)** (дзеркало: [seeedstudio.com](https://files.seeedstudio.com/products/Feetech/108090023_STS3215-C001_Datasheet.pdf))
- **[Waveshare Wiki: ST3215 Servo](https://www.waveshare.com/wiki/ST3215_Servo)**

## Протокол пакетів (як `st3215.py` спілкується з сервоприводом)

Протокол Feetech SMS/STS, пакетний, з контрольною сумою замість CRC:

- Пакет: `0xFF 0xFF | id | length | instruction | параметри... | checksum`
- `checksum = (~(id + length + instruction + сума(параметрів))) & 0xFF`
- Використовувані тут інструкції: `PING (1)`, `READ (2)`, `WRITE (3)`
- На відміну від шини TMC2209 (простий резистор, що з'єднує TX з RX, тож кожен байт повертається як ехо і має бути вичитаний), адаптер Waveshare Bus Servo Adapter (A) — справжній трансивер: TX/RX лишаються електрично окремими, тож на цій шині **немає жодного самоехо** для вичитування. Див. докстрінг модуля `st3215.py` та [TROUBLESHOOTING.md](TROUBLESHOOTING.md) щодо бага, спричиненого цією різницею, коли патерн вичитування ехо з шини TMC2209 помилково скопіювали сюди.
- Кожна відповідь несе байт статусу/помилки (`reply[4]`), який декодується `get_error_text()` у прапори `ERRBIT_*` нижче — саме з нього формується список `ERROR(...)` в `diag_summary()`.

## Таблиця регістрів

| Адр | Регістр | Байтів | Доступ | Використання |
|---|---|---|---|---|
| 3 | MODEL_L (+4: MODEL_H) | 2 | R | Номер моделі (`ping_verbose()`) |
| 9 | MIN_ANGLE_LIMIT_L (+10: _H) | 2 | R/W (EPROM) | Оголошено, але наразі не використовується цим кодом |
| 11 | MAX_ANGLE_LIMIT_L (+12: _H) | 2 | R/W (EPROM) | Оголошено, але наразі не використовується цим кодом |
| 33 | MODE | 1 | R/W (EPROM) | Оголошено, але наразі не використовується цим кодом |
| 40 | TORQUE_ENABLE | 1 | R/W | Увімкнення/вимкнення моменту (`torque_enable()`) |
| 41 | ACC | 1 | R/W | Прискорення, сирі одиниці 0-254 (`set_acceleration()`) — точне співвідношення прискорення до одиниці задокументовано непослідовно, підбирається на око |
| 42 | GOAL_POSITION_L (+43: _H) | 2 | R/W | Цільова позиція (`set_goal()`/`set_goal_deg()`) |
| 44 | GOAL_TIME_L (+45: _H) | 2 | R/W | Тривалість руху; цей драйвер лишає 0, щоб сервопривід використовував GOAL_SPEED замість фіксованого часу |
| 46 | GOAL_SPEED_L (+47: _H) | 2 | R/W | Швидкість руху, сирі внутрішні одиниці сервопривода (типово ~0-3400) |
| 56 | PRESENT_POSITION_L (+57: _H) | 2 | R | Жива абсолютна позиція (`read_position()`/`read_position_deg()`) |
| 60 | PRESENT_LOAD_L (+61: _H) | 2 | R | Живе навантаження: біти 0-9 величина, біт 10 напрямок (`read_load()`) — див. примітку нижче |
| 62 | PRESENT_VOLTAGE | 1 | R | Жива напруга живлення, сире значення × 0.1 = вольти (`read_voltage()`) |
| 63 | PRESENT_TEMPERATURE | 1 | R | Жива температура, сире значення вже в °C (`read_temperature()`) |
| 66 | MOVING | 1 | R | Чи рухається сервопривід зараз (`is_moving()`) |
| 69 | PRESENT_CURRENT_L (+70: _H) | 2 | R | Живе споживання струму, сире значення × 6.5 = мА (`read_current_ma()`) |

**EPROM**-регістри зберігаються між циклами живлення, але потребують розблокування EPROM (`LockEprom`/`unLockEprom` в офіційному SDK — не реалізовано в `st3215.py`, оскільки цей драйвер ніколи їх не записує).

### PRESENT_LOAD: величина не підтверджена незалежно як відсоток

Деякі неофіційні довідники по регістрах описують PRESENT_LOAD як 0-1000, що представляє 0-100.0% максимального моменту, але це не було знайдено достатньо чітко сформульованим в офіційній специфікації, щоб на це покладатись. Тому `read_load()` повертає сиру знакову величину (0-1023, від'ємну, якщо встановлено біт напрямку), а не стверджує масштаб у відсотках, який не можна підтвердити.

## Байт статусу/помилки (`ERRBIT_*` в `st3215.py`)

Повертається як байт з індексом 4 кожного пакета-відповіді — це не окремо адресований регістр, а найближчий еквівалент прапорів несправностей GSTAT/DRV_STATUS у TMC2209, і саме з нього формується список `ERROR(...)` в `diag_summary()`:

| Біт | Константа | Значення |
|---|---|---|
| 0 | `ERRBIT_VOLTAGE` | Помилка вхідної напруги |
| 1 | `ERRBIT_ANGLE` | Помилка датчика кута |
| 2 | `ERRBIT_OVERHEAT` | Помилка перегріву |
| 3 | `ERRBIT_OVERELE` | Помилка перевищення струму (OverEle) |
| 5 | `ERRBIT_OVERLOAD` | Помилка перевантаження |

Вони збігаються з константами бітів помилок офіційного `scservo_sdk` Waveshare/Feetech (`protocol_packet_handler.py`), тому `get_result_text()`/`get_error_text()` читаються так само, як вивід вендорених демо-скриптів `STServo_Python`.

## Конвертація позиції/кута

`UNITS_PER_REV = 4096` (12-бітний датчик позиції, магнітний енкодер, один повний оберт 360°):

```
deg_to_units(deg) = round(deg / 360 * 4096), обмежено 0..4095
units_to_deg(units) = units * 360 / 4096
```

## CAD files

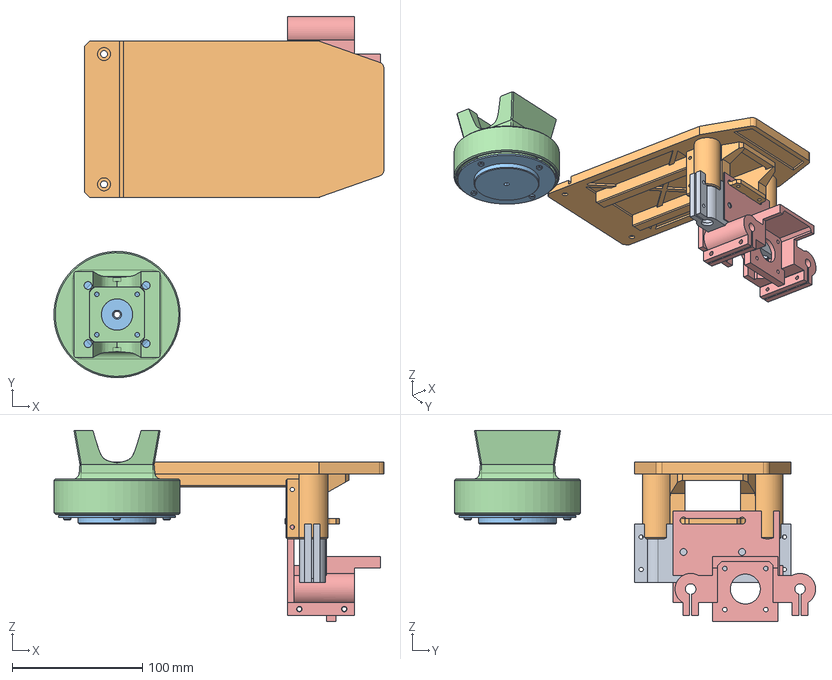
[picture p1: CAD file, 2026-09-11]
freecad/motor3D2.FCStd
253.4 x 277.5 x 146.8 mm
carriage
nema17HolderWithRail
top
steperHolder
nema17XHolder

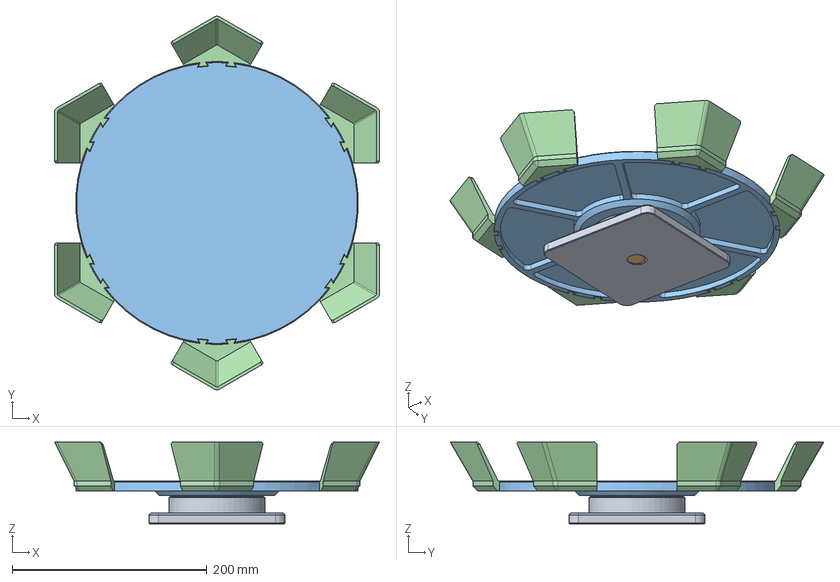
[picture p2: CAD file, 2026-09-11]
table_models/TurnTable 290mm.stp
333.4 x 383.4 x 84.0 mm
Base
Bearing Lock
Plate 290
Target 290 x 6

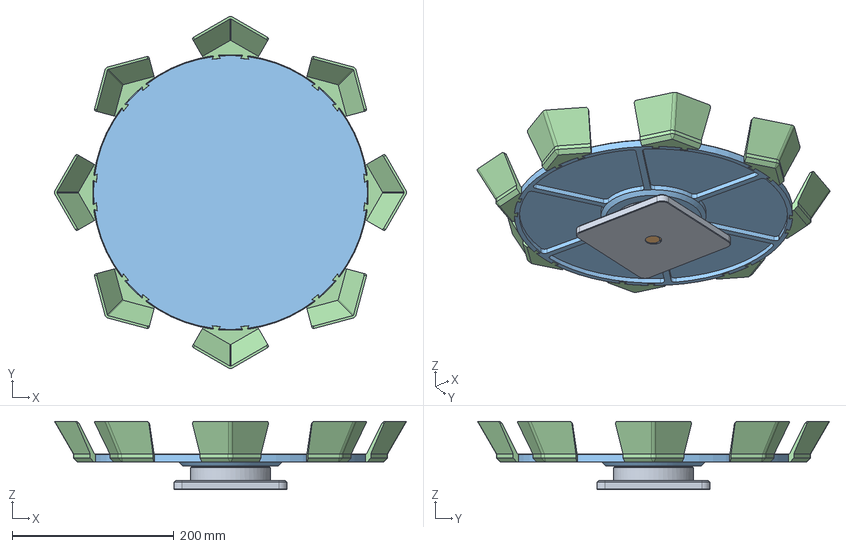
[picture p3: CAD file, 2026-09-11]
table_models/TurnTable 340mm.stp
434.6 x 434.6 x 84.0 mm
Base
Bearing Lock
Plate 340
Target 340 x 8

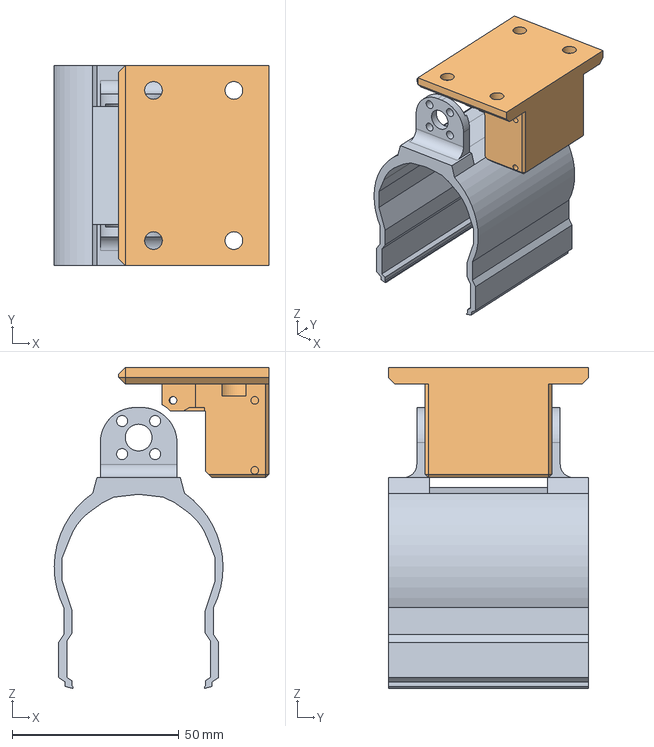
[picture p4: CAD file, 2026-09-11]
freecad/cr_servoSTS3215.FCStd
64.3 x 60.0 x 96.2 mm
3dCameraHolder
servoHolder

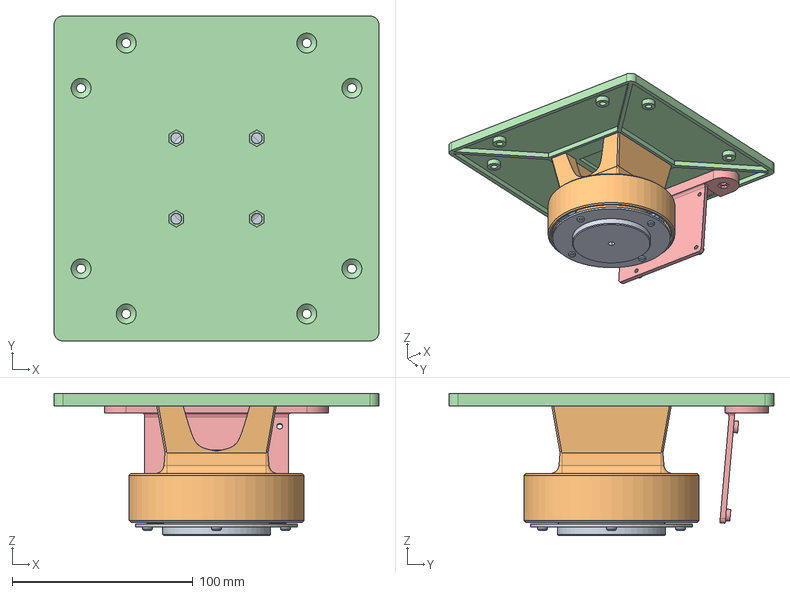
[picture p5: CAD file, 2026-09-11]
freecad/stepper2.FCStd
180.0 x 180.0 x 78.8 mm
top
steperHolder
washer
base
pisocHolder

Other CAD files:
freecad/motor3Dv3.FCStd

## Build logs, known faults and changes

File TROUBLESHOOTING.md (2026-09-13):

*[Українська версія](TROUBLESHOOTING.uk.md)*

# Troubleshooting log

## ST3215 servo: no response on the bus (RESOLVED — driver bug, not hardware)

**Symptom:** after wiring the ST3215 servo through a Waveshare Bus Servo Adapter (A) into the SKR Pico's `Laser` connector (IO0/IO1, see `PINOUT.md`), `scanner_rig.py`/`st3215.py` got `OSError: no reply` on every call — `ping()`, `read_position()`, `set_goal_deg()`.

**Root cause:** `st3215.py`'s `write_register`/`read_register` unconditionally drained a "self-echo" after every UART write, copying the pattern from `tmc2209.py` where that's correct — on the TMC2209 bus, TX is wired straight into RX through a resistor, so every transmitted byte genuinely echoes back and must be drained before the real reply. The Waveshare adapter is a different kind of circuit: it's a real transceiver, so our TX and RX stay electrically separate right up to the adapter, and there is **no self-echo on this bus at all**. The servo replies within microseconds - faster than the bogus "echo" read's timeout - so that drain call was silently swallowing the servo's real reply every single time, then timing out waiting for a second reply that would never come. This happened identically regardless of servo unit, cable, jumper position, or baud rate, which is exactly why none of those varied.

**How it was found:** extensive hardware-side diagnosis (MCU-pin loopback test, cable swap, full baud/ID sweep, independent verification against the official Waveshare `scservo_sdk` run directly against the adapter over USB) ruled out every piece of hardware in the chain, including the servo units themselves - see the diagnostic steps below, still accurate as a record of what was checked, even though the conclusion drawn from them at the time was wrong. The actual bug was found by comparing against a working third-party MicroPython driver, which didn't drain any echo unless an explicit half-duplex `dir_pin` was configured (see `sts3215.py` for that reference implementation) - the SKR Pico/Waveshare-adapter setup here doesn't use one.

**Fix:** removed the erroneous `self._read_exact(len(pkt))` call after `self.uart.write(pkt)` in `st3215.py`'s `_txrx`. Confirmed working end-to-end through the SKR Pico afterward: `ping()`, `read_position()`, and `set_goal_deg()` all succeed and the servo physically moves.

**Diagnostic steps taken along the way (all correctly ruled out hardware, which was never actually the problem):**

1. **Adapter jumper position** — confirmed `A` (external-MCU UART mode) for SKR Pico use, `B` for direct-PC/USB use. Both work correctly with the fixed driver; the earlier confusion was largely from having the jumper in the wrong position during a couple of PC-direct isolation tests, compounding the real (driver) bug.
2. **Adapter power** — power LED lit, confirmed powered.
3. **TX/RX crossing** — confirmed correct (SKR Pico TX → adapter RX, SKR Pico RX → adapter TX).
4. **MCU-side loopback test** — shorted IO0/IO1 together directly at the SKR Pico connector, sent raw bytes over `UART(0, tx=Pin(0), rx=Pin(1))`, got them back. Confirmed the RP2040 pins/UART0 hardware healthy (this was always true; the bug was downstream in application-level packet handling, not the hardware UART).
5. **Baud rate / full ID sweep**, **cable swap**, **servo swap**, **independent official-SDK verification over direct USB** — all done, all pointed at "the servo/adapter doesn't answer", because the *same class of bug* (an extra blocking read before reading the real reply) doesn't exist in the official SDK or in a correctly-written driver, so those channels worked once the jumper was set correctly - which is what made it look like a hardware fault specific to the SKR-Pico path.

## Y/Z sensorless homing (StallGuard/DIAG): no trip detected (IN PROGRESS — several real bugs fixed, final verification pending real hardware assembly)

**Symptom:** `Y HOME`/`bounce_task`'s DIAG-based stall detection never tripped, at any `SGTHRS` from 0 to 254, under either stealthChop or spreadCycle, at 400mA or 800mA, at 150 or 500 steps/sec, and with the axis genuinely blocked by hand (via the gear, not the bare motor shaft) for many seconds at a time.

**Multiple real bugs found and fixed along the way, in the order discovered:**

1. **`asyncio.sleep_us` doesn't exist in this uasyncio build** — a separate, earlier bug (see git history) that meant `x_task`/`bounce_task` had never actually run through the real event loop before; fixed by switching to `sleep_ms` plus a brief blocking `time.sleep_us` just for the STEP pulse width.
2. **stealthChop makes StallGuard noisy.** Raw `SG_RESULT`, read live during free spinning, bounced erratically between 0 and 24 under stealthChop - polling it directly (the first approach tried) was unusable. Switching to spreadCycle during homing (`motor.enable_uart_mode(spreadcycle=True)`, restored afterward) cleaned this up to a stable 0-4 range. This matches the Voron sensorless-homing guide, which mandates `stealthchop_threshold: 0` (i.e. spreadCycle) for exactly this reason.
3. **`TCOOLTHRS` direction was backwards.** It was first set to a *low* value (3000) on the theory that this "activates StallGuard at low speed." The Trinamic datasheet phrase "lower threshold velocity for switching **on**" actually means the opposite: TCOOLTHRS is a *minimum* speed, and StallGuard/DIAG is active *above* it. A low TCOOLTHRS require a *high* speed to activate - at our actual bounce/home speeds this most likely disabled DIAG outright. Confirmed against [Chr157i4n/PyTmcStepper's `_tmc_stallguard.py`](https://github.com/Chr157i4n/PyTmcStepper/blob/main/src/tmc_driver/_tmc_stallguard.py), which derives `TCOOLTHRS` from a *minimum* homing speed. Fixed by setting it back to the register maximum (`0xFFFFF`), i.e. "active at any practical speed."
4. **Reduced current improves StallGuard's usable signal during homing** specifically - the Voron guide uses roughly half the normal run current (~0.49A) just for the homing move, restored afterward. Implemented as `HOME_CURRENT_MA`, applied/restored in `home_axis`'s `try/finally` alongside the spreadCycle toggle.
5. **Home speed was too low.** 150 steps/sec (at 16 microsteps, under 10 full steps/sec) doesn't give StallGuard enough real velocity for a clean reading. Raised the default to 500.
6. **Jumper cap position is still unresolved - a false lead, corrected.** A `Y-DIAG` pin-level check (no pull / `PULL_UP` / `PULL_DOWN` all reading a stable `0`) suggested the pin was actively driven rather than floating, so `Y-DIAG`/`Z-DIAG` jumper caps were physically swapped as a test. Afterward `y_diag.value()`/`z_diag.value()` did start reading live and tracking `SGTHRS` changes - but it turned out the caps had actually been moved to the two *other*, otherwise-unused DIAG headers (`X-DIAG`/`E0-DIAG`), not swapped between `Y-DIAG` and `Z-DIAG` as intended, leaving `Y-DIAG`/`Z-DIAG` uncapped. With no jumper connecting DIAG to the STOP header at all, `Y-STOP`/`Z-STOP` should just be floating GPIOs - the "live-looking" readings that correlated with `SGTHRS` and motor activity were almost certainly EMI/crosstalk from the adjacent STEP pulses on a floating pin, not a real StallGuard signal. **This result is not trustworthy and should be disregarded.** The caps need to go back on `Y-DIAG`/`Z-DIAG` specifically (confirmed by an earlier photo of the correct position) before re-testing.

**Update after correctly reseating the caps on `Y-DIAG`/`Z-DIAG`:** idle `y_diag.value()` now correctly reads `0` (matching `z_diag`, and no longer the stuck-`1` seen with the caps in the wrong (empty) headers). Comparing against [AndreaFavero71/stepper_sensorless_homing](https://github.com/AndreaFavero71/stepper_sensorless_homing/blob/main/src/board_V2/stepper.py) - which computes its expected StallGuard baseline as *proportional to step frequency* (`min_sg_expected = 0.15 * stepper_freq`), at speeds of 400-1200 Hz **full steps** - suggested our homing speed was still far too slow: 500 "steps/sec" in this codebase means *microstep* pulses at 16 microsteps, i.e. ~31 full steps/sec, roughly 15-40x slower than that reference. Raising `HOME_SPEED_DEFAULT` to 3000 (still microsteps/sec) showed `SG_RESULT` peaks rising with speed (500→8, 2000→10, 4000→12, 8000→20 in a quick sweep), consistent with that theory.

**Cross-check against a confirmed-working hand-stall test:** [`google_test_stall_guard.py`](google_test_stall_guard.py) (a separate MicroPython prototype, targeting the same Y driver/pins) reportedly did detect a hand-applied stall, using `SGTHRS=100`, a 1kHz step pulse rate (500us half-period - i.e. `HOME_SPEED_DEFAULT` in this codebase's units), and a moderate `IRUN=14` current chosen specifically to be "spinnable but stoppable by hand". Its `GCONF=0x1C` sets the same bit this codebase calls `en_spreadcycle` to `1`, labeled "StealthChop2" in that script's comment - given our own measured noise-vs-mode data (0-24 noisy vs 0-4 clean), bit=1 is spreadCycle here, not stealthChop, so that prototype's success is consistent with our finding rather than contradicting it (the comment there is just mislabeled). Adopted `SGTHRS=100` and `HOME_SPEED_DEFAULT=1000` as this codebase's new defaults on the strength of that confirmed result - both were previously untested in combination with the correctly-seated jumper caps.

**Architecture pivot: `home_axis` now polls `SG_RESULT` over UART, not the DIAG pin.** The user's own `google_test_stall_guard.py` (confirmed working on this exact Y motor/pins) never reads DIAG at all - it detects stalls purely by reading register `0x41` (`SG_RESULT`) directly and comparing it against a plain threshold (`sg_val < 20`). `home_axis` was rewritten to do the same: poll `read_stallguard_result()` roughly every 100ms during the homing move, comparing the raw value against `sgthrs` directly (not the doubled on-chip comparison `is_stalled()` used, which is still what the old DIAG-pin code path implicitly relied on). This also picked up the same script's acceleration ramp (jumping straight to full step rate from a stop can itself look like a stall) and its `IRUN=14` current (≈830mA via our own CS formula - `HOME_CURRENT_MA` was previously 400, i.e. CS≈6, much weaker than the reference).

**Register-readback diagnostic was a false lead - `IHOLD_IRUN`/`TCOOLTHRS`/`SGTHRS` are write-only on this chip.** While chasing repeated false/instant stall trips after the pivot above, `y.read(0x10)` / `read(0x14)` / `read(0x40)` were used to verify `set_current()`/`enable_stallguard()` had actually taken effect - all three read back as `0x00000000` even right after writing, while `GCONF`/`CHOPCONF`/`PWMCONF` (all R+W registers) read back correctly. This looked like a register-write bug (tried adding a 2ms post-write delay, matching `google_test_stall_guard.py`'s `tmc_write()` - no change). It turned out to be nothing: per the TMC2209 datasheet's register-access table, `IHOLD_IRUN` (0x10), `TCOOLTHRS` (0x14), and `SGTHRS` (0x40) are **write-only** registers on this chip - reading them always returns 0 regardless of whether the write succeeded. Only `GCONF`/`CHOPCONF`/`PWMCONF` (marked R+W) are meaningful to read back; `TSTEP`, `SG_RESULT`, `DRV_STATUS`, `PWM_SCALE` are the readable status registers. The 2ms delay was reverted (harmless but solving a problem that didn't exist). **The real cause of the false/instant stall trips remains open** - see next.

**Current status:** DIAG connectivity is confirmed correct on both axes (idle-low, as expected), and defaults now match a value combination confirmed working elsewhere on the same hardware. `home_axis` still trips almost immediately (e.g. `pos=-262` to `-265`, a few hundred milliseconds in) even after the UART-polling pivot, the ramp-up, and the current fix above - none of which has resolved it yet, and the register-readback lead turned out to be a false one (see above). Given the current write is real (just unverifiable by readback), this is NOT explained by the motor running at near-zero current. **Hand-blocking the mechanism by the gear was tried repeatedly throughout this investigation and never moved `SG_RESULT` measurably** in *our* tests, even at reduced current - possibly a gear reduction between the finger and the motor shaft damps the reflected load more than the direct-drive belt/carriage setups (or the `google_test_stall_guard.py` script's own setup) where manual-block testing works. The user has confirmed this is reproducible on the exact same already-assembled hardware as the working reference script (not a wiring/reassembly difference), so the next things worth checking: whether `bounce_task`'s (or a prior `home_axis` run's) leftover state - e.g. `enable_uart_mode(spreadcycle=False)`/`set_current(run_current_ma)` restored in `finally` - is somehow interacting with the *next* `HOME` call's assumptions; whether `STALL_SETTLE_STEPS`/`RAMP_STEPS` are actually being reached before the first check fires; and printing the raw `sg` value on every check (not just at the moment of a confirmed stall) to see what it's actually reading during the supposedly-free-spinning portion of the move.

## TMC2209 UART setup: PWMCONF/pwm_autoscale was missing

`enable_uart_mode()` configured `GCONF` (`pdn_disable`, `mstep_reg_select`, and the spreadCycle/stealthChop bit) and `set_current()` configured `IHOLD_IRUN` correctly, but neither ever touched `PWMCONF` (`0x70`). StealthChop's current-regulation loop needs `pwm_autoscale` (bit 18) and `pwm_autograd` (bit 19) enabled to actually adapt PWM amplitude to the motor/load; without them it runs open-loop off whatever `pwm_ofs`/`pwm_grad` happen to be at reset, which is rougher/louder than a properly initialized StealthChop setup. Fixed with a read-modify-write in `enable_uart_mode()` (`pwmconf |= (1<<18)|(1<<19)`) so the factory `pwm_freq`/`pwm_grad`/`pwm_ofs` defaults are left alone. Confirmed on real hardware: `PWMCONF` now reads back with both bits set after `setup_motors()`.

This doesn't affect the sensorless-homing investigation above (homing deliberately runs in spreadCycle, not stealthChop) - it's a quality-of-life fix for the *normal* bouncing/rotation moves, which do use stealthChop.

## Setup notes for the official Waveshare SDK (`STServo_Python/`)

The demo scripts in `STServo_Python/` came from Waveshare without their `scservo_sdk` dependency — it's vendored separately in `scservo_sdk/` (fetched from the official `ftservo/FTServo_Python` repo) so `sys.path.append("..")` + `from scservo_sdk import *` resolves.

Each script hardcodes `DEVICENAME` (Windows `COM*` by default) — set it to the actual device, e.g. `/dev/ttyACM0` on Linux. `ping.py`'s `BAUDRATE` was also hardcoded to `115200`, not the ST/STS-series factory default `1000000` — fixed in this repo's copy.

`ping.py` (and others) use `termios` at import time to support a "press any key" prompt, which throws `termios.error: (25, 'Inappropriate ioctl for device')` if stdin isn't a real TTY (e.g. run from a non-interactive script/CI). Run interactively, or wrap with `script -qec "python3 ping.py" /dev/null` to allocate a pseudo-terminal.

For quick command-line checks without the keypress prompt, use `STServo_Python/simple_ping.py` and `STServo_Python/simple_rotate.py`.

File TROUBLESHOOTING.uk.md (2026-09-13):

*[English version](TROUBLESHOOTING.md)*

# Журнал діагностики проблем

## Сервопривід ST3215: немає відповіді на шині (ВИРІШЕНО — баг у драйвері, не апаратна проблема)

**Симптом:** після підключення ST3215 через Waveshare Bus Servo Adapter (A) до конектора `Laser` SKR Pico (IO0/IO1, див. `PINOUT.md`), `scanner_rig.py`/`st3215.py` отримували `OSError: no reply` на кожен виклик — `ping()`, `read_position()`, `set_goal_deg()`.

**Справжня причина:** `write_register`/`read_register` у `st3215.py` безумовно "вичитували ехо" після кожного запису в UART — цей патерн скопійований з `tmc2209.py`, де він правильний: на шині TMC2209 TX з'єднаний напряму з RX через резистор, тож кожен відправлений байт справді повертається як ехо і його треба вичитати перед реальною відповіддю. Адаптер Waveshare — інша схема: це справжній трансивер, тому наші TX і RX лишаються електрично окремими аж до самого адаптера, і на цій шині **взагалі немає жодного ехо**. Сервопривід відповідає за мікросекунди — швидше, ніж спрацьовує таймаут фіктивного "вичитування ехо" — тож цей виклик щоразу мовчки проковтував справжню відповідь сервопривода, а потім код чекав на другу відповідь, якої ніколи не буде. Це відтворювалось однаково незалежно від конкретного сервопривода, кабелю, позиції джампера чи швидкості — саме тому жоден з цих факторів нічого не міняв.

**Як знайдено:** масштабна апаратна діагностика (loopback-тест на пінах MCU, заміна кабелю, повний перебір швидкостей/ID, незалежна перевірка офіційним Waveshare `scservo_sdk` напряму через USB) виключила кожен апаратний компонент у ланцюжку, включно з самими сервоприводами — кроки діагностики нижче лишаються точним записом того, що перевірялось, хоча висновок, зроблений з них на той момент, був невірний. Справжній баг знайдено порівнянням зі стороннім робочим MicroPython-драйвером, який не вичитував жодного ехо, якщо явно не налаштований напівдуплексний `dir_pin` (див. `sts3215.py` як приклад реалізації) — у цій конфігурації SKR Pico + адаптер Waveshare такий пін не використовується.

**Виправлення:** прибрано помилковий виклик `self._read_exact(len(pkt))` після `self.uart.write(pkt)` в `_txrx` в `st3215.py`. Після цього перевірено повний цикл через SKR Pico: `ping()`, `read_position()` та `set_goal_deg()` — усе працює, сервопривід фізично рухається.

**Кроки діагностики по дорозі (усі правильно виключили апаратну частину, яка насправді ніколи не була проблемою):**

1. **Позиція джампера на адаптері** — підтверджено: `A` для UART-режиму з SKR Pico, `B` для прямого підключення до ПК/USB. З виправленим драйвером обидва режими працюють коректно; попередня плутанина здебільшого йшла від того, що джампер стояв не в тій позиції під час кількох ізолюючих тестів через ПК, накладаючись на справжній (програмний) баг.
2. **Живлення адаптера** — світлодіод горить, живлення підтверджено.
3. **Схрещення TX/RX** — підтверджено правильне (TX SKR Pico → RX адаптера, RX SKR Pico → TX адаптера).
4. **Loopback-тест на стороні MCU** — замкнули IO0/IO1 прямо на конекторі SKR Pico, відправили сирі байти через `UART(0, tx=Pin(0), rx=Pin(1))`, отримали назад. Підтвердило справність апаратної частини RP2040/UART0 (це завжди було правдою; баг був нижче за рівнем — в обробці пакетів на рівні застосунку, а не в апаратному UART).
5. **Перебір швидкостей/ID**, **заміна кабелю**, **заміна сервопривода**, **незалежна перевірка офіційним SDK напряму через USB** — усе це вказувало на "сервопривід/адаптер не відповідає", бо *такого ж класу баг* (зайве блокуюче читання перед реальною відповіддю) відсутній в офіційному SDK чи в правильно написаному драйвері, тож ці канали працювали одразу після правильного налаштування джампера — саме це й створювало враження апаратної несправності, специфічної для шляху через SKR Pico.

## Sensorless homing Y/Z (StallGuard/DIAG): не спрацьовує (В ПРОЦЕСІ — знайдено кілька реальних багів, фінальна перевірка чекає монтажу в реальну систему)

**Симптом:** DIAG-детекція застою в `Y HOME`/`bounce_task` жодного разу не спрацювала — ні на `SGTHRS` від 0 до 254, ні на stealthChop/spreadCycle, ні на 400/800мА, ні на 150/500 кроків/сек, ні при реальному блокуванні осі рукою (за шестерню, не за голий вал) протягом багатьох секунд.

**Кілька реальних багів знайдено й виправлено по дорозі, в порядку виявлення:**

1. **`asyncio.sleep_us` не існує в цій збірці uasyncio** — окремий, раніше знайдений баг (див. історію git): `x_task`/`bounce_task` фактично ніколи не проходили через справжній event loop. Виправлено переходом на `sleep_ms` + коротку блокуючу `time.sleep_us` лише на сам STEP-імпульс.
2. **stealthChop робить StallGuard шумним.** Сире `SG_RESULT`, зчитане наживо під час вільного ходу, хаотично стрибало між 0 і 24 під stealthChop — пряме опитування (перший випробуваний підхід) було непридатне. Перехід на spreadCycle на час хомінгу (`motor.enable_uart_mode(spreadcycle=True)`, повертається назад після) очистив це до стабільного діапазону 0-4. Це збігається з гайдом VORON по sensorless homing, який вимагає `stealthchop_threshold: 0` (тобто spreadCycle) саме з цієї причини.
3. **Напрямок `TCOOLTHRS` був переплутаний.** Спершу виставили *низьке* значення (3000), думаючи, що це "активує StallGuard на низькій швидкості". Фраза з даташиту Trinamic "lower threshold velocity for switching **on**" насправді означає протилежне: TCOOLTHRS — це *мінімальна* швидкість, і StallGuard/DIAG активний *вище* неї. Низький TCOOLTHRS вимагає *високої* швидкості для активації — на наших реальних швидкостях руху це, найімовірніше, повністю вимикало DIAG. Підтверджено звіркою з [Chr157i4n/PyTmcStepper `_tmc_stallguard.py`](https://github.com/Chr157i4n/PyTmcStepper/blob/main/src/tmc_driver/_tmc_stallguard.py), де TCOOLTHRS обчислюється з *мінімальної* швидкості хомінгу. Виправлено поверненням на максимум регістра (`0xFFFFF`), тобто "активний на будь-якій практичній швидкості".
4. **Знижений струм покращує сигнал StallGuard саме під час хомінгу** — гайд VORON використовує приблизно половину робочого струму (~0.49A) лише на час руху хомінгу, з відновленням після. Реалізовано як `HOME_CURRENT_MA`, застосовується/відновлюється в `home_axis` через `try/finally` разом з перемиканням spreadCycle.
5. **Швидкість хомінгу була занадто низькою.** 150 кроків/сек (при 16 мікрокроках — менше 10 повних кроків/сек) не дає StallGuard достатньої реальної швидкості для чистого сигналу. Дефолт піднято до 500.
6. **Позиція джампера-ковпачка досі не з'ясована — хибний слід, скасовано.** Перевірка на рівні піна `Y-DIAG` (без підтяжки / `PULL_UP` / `PULL_DOWN` — всі три давали стабільний `0`) наштовхнула на думку, що пін активно керується, а не висить у повітрі, тож ковпачки `Y-DIAG`/`Z-DIAG` фізично переставили як тест. Після цього `y_diag.value()`/`z_diag.value()` почали читатись "живо" і відслідковувати зміни `SGTHRS` — але виявилось, що ковпачки насправді переставили на два **інші**, до того не використовувані роз'єми DIAG (`X-DIAG`/`E0-DIAG`), а не поміняли місцями між `Y-DIAG` і `Z-DIAG`, як планувалось, залишивши `Y-DIAG`/`Z-DIAG` без ковпачків. Без ковпачка, що з'єднує DIAG зі STOP-конектором, `Y-STOP`/`Z-STOP` мають просто висіти в повітрі (floating) — "живі на вигляд" показники, що корелювали з `SGTHRS` і активністю мотора, майже напевно були наведенням/перехресною завадою від сусідніх STEP-імпульсів на плаваючому піні, а не справжнім сигналом StallGuard. **Цей результат недостовірний і має бути відкинутий.** Ковпачки треба повернути саме на `Y-DIAG`/`Z-DIAG` (підтверджено раніше зробленим фото правильної позиції) перед повторною перевіркою.

**Оновлення після правильного встановлення ковпачків на `Y-DIAG`/`Z-DIAG`:** `y_diag.value()` у стані спокою тепер коректно читає `0` (як і `z_diag`, а не "застряглий" `1`, який був з ковпачками на порожніх роз'ємах). Порівняння з [AndreaFavero71/stepper_sensorless_homing](https://github.com/AndreaFavero71/stepper_sensorless_homing/blob/main/src/board_V2/stepper.py) — де очікуваний базовий рівень StallGuard обчислюється *пропорційно частоті кроків* (`min_sg_expected = 0.15 * stepper_freq`) на швидкостях 400-1200 Гц **повних кроків** — показало, що наша швидкість хомінгу була ще занадто низькою: 500 "кроків/сек" у цьому коді означає *мікрокрокові* імпульси при 16 мікрокроках, тобто ~31 повний крок/сек — приблизно в 15-40 разів повільніше за цей приклад. Підняття `HOME_SPEED_DEFAULT` до 3000 (все ще мікрокроки/сек) показало зростання піків `SG_RESULT` зі швидкістю (500→8, 2000→10, 4000→12, 8000→20 у швидкому тесті), що узгоджується з цією теорією.

**Звірка з підтверджено робочим тестом ручного блокування:** [`google_test_stall_guard.py`](google_test_stall_guard.py) (окремий MicroPython-прототип, націлений на той самий драйвер/піни Y) за словами користувача успішно детектував ручне блокування, використовуючи `SGTHRS=100`, частоту кроків 1кГц (500мкс напівперіод — тобто `HOME_SPEED_DEFAULT` в термінах цього коду), і помірний струм `IRUN=14`, обраний спеціально "щоб крутився, але його можна було зупинити рукою". Його `GCONF=0x1C` виставляє той самий біт, який у цьому коді називається `en_spreadcycle`, в `1`, підписаний коментарем "StealthChop2" — але за нашими ж вимірами шуму (0-24 шумно проти 0-4 чисто), біт=1 тут означає spreadCycle, не stealthChop, тож успіх того прототипу узгоджується з нашим висновком, а не суперечить йому (коментар там просто помилковий). Прийнято `SGTHRS=100` і `HOME_SPEED_DEFAULT=1000` як нові дефолти цього коду на основі цього підтвердженого результату — обидва раніше не тестувались у поєднанні з правильно встановленими ковпачками джампера.

**Архітектурний поворот: `home_axis` тепер опитує `SG_RESULT` через UART, а не пін DIAG.** Власний скрипт користувача `google_test_stall_guard.py` (підтверджено робочий на тому самому моторі/пінах Y) взагалі не читає DIAG — він детектує застій виключно читанням регістра `0x41` (`SG_RESULT`) і порівнянням з простим порогом (`sg_val < 20`). `home_axis` переписано так само: опитує `read_stallguard_result()` приблизно раз на 100мс під час руху хомінгу, порівнюючи сире значення напряму з `sgthrs` (не через подвоєне порівняння на чіпі, яке використовував `is_stalled()` зі старого шляху на основі DIAG-піна). Заразом перенесено розгін з того ж скрипта (стрибок одразу на повну швидкість з нуля сам по собі може виглядати як застій) та його струм `IRUN=14` (~830мА за нашою ж формулою CS — `HOME_CURRENT_MA` раніше було 400, тобто CS≈6, значно слабше за приклад).

**Діагностика через зчитування регістрів була хибним слідом — `IHOLD_IRUN`/`TCOOLTHRS`/`SGTHRS` на цьому чіпі write-only.** Під час пошуку причини повторюваних миттєвих хибних спрацювань хомінгу після повороту вище, `y.read(0x10)` / `read(0x14)` / `read(0x40)` використовувались, щоб перевірити, чи `set_current()`/`enable_stallguard()` дійсно застосувались — усі три читались як `0x00000000` навіть одразу після запису, тоді як `GCONF`/`CHOPCONF`/`PWMCONF` (усі регістри R+W) читались коректно. Це виглядало як баг запису в регістри (спробували додати затримку 2мс після запису, за прикладом `tmc_write()` з `google_test_stall_guard.py` — без змін). Виявилось, що проблеми не було: за таблицею доступу до регістрів з даташиту TMC2209, `IHOLD_IRUN` (0x10), `TCOOLTHRS` (0x14) та `SGTHRS` (0x40) — **write-only** регістри на цьому чіпі: читання завжди повертає 0 незалежно від того, чи запис пройшов успішно. Читати назад має сенс лише `GCONF`/`CHOPCONF`/`PWMCONF` (позначені R+W); `TSTEP`, `SG_RESULT`, `DRV_STATUS`, `PWM_SCALE` — регістри стану, які читаються. Затримку 2мс прибрано (нешкідлива, але вирішувала неіснуючу проблему). **Справжня причина хибних/миттєвих спрацювань хомінгу лишається невідомою** — див. далі.

**Поточний статус:** зв'язок DIAG підтверджено правильним на обох осях (idle-low, як і очікувалось), а дефолти тепер відповідають комбінації значень, підтвердженій робочою на тому ж залізі. `home_axis` досі спрацьовує майже миттєво (наприклад, `pos=-262`...`-265`, за частку секунди) навіть після повороту на опитування SG_RESULT через UART, додавання розгону і виправлення струму вище — жодне з цього поки не вирішило проблему, а слід із зчитуванням регістрів виявився хибним (див. вище). Оскільки запис струму насправді відбувається (просто його не можна перевірити зчитуванням), це НЕ пояснюється роботою мотора на майже нульовому струмі. **Блокування механізму рукою за шестерню пробували неодноразово протягом усього розслідування, і воно жодного разу помітно не зрушило `SG_RESULT`** саме в наших тестах, навіть при зниженому струмі — можливо, редуктор між пальцем і валом мотора гасить відбите навантаження сильніше, ніж у прямому приводі паском/каріткою (чи в самому прототипі `google_test_stall_guard.py`), де ручне блокування спрацьовує. Користувач підтвердив, що це відтворюється на тому самому вже змонтованому залізі, що й робочий приклад (не різниця в підключенні/монтажі), тож наступне, що варто перевірити: чи не впливає стан, залишений `bounce_task` (або попереднім запуском `home_axis`) — наприклад, `enable_uart_mode(spreadcycle=False)`/`set_current(run_current_ma)`, відновлені в `finally` — на припущення *наступного* виклику `HOME`; чи справді досягаються `STALL_SETTLE_STEPS`/`RAMP_STEPS` до першої перевірки; і виведення сирого значення `sg` при **кожній** перевірці (не лише в момент підтвердженого застою), щоб побачити, що насправді читається під час нібито вільного обертання.

## Налаштування TMC2209 через UART: бракувало PWMCONF/pwm_autoscale

`enable_uart_mode()` налаштовував `GCONF` (`pdn_disable`, `mstep_reg_select`, біт spreadCycle/stealthChop), а `set_current()` — коректно `IHOLD_IRUN`, але жоден з них ніколи не торкався `PWMCONF` (`0x70`). Контур регулювання струму StealthChop потребує увімкнених `pwm_autoscale` (біт 18) і `pwm_autograd` (біт 19), щоб реально підлаштовувати амплітуду ШІМ під мотор/навантаження; без них він працює "розімкнено" на тому, які `pwm_ofs`/`pwm_grad` є після скидання — це грубіше й гучніше за правильно ініціалізований StealthChop. Виправлено через read-modify-write в `enable_uart_mode()` (`pwmconf |= (1<<18)|(1<<19)`), щоб не чіпати заводські `pwm_freq`/`pwm_grad`/`pwm_ofs`. Підтверджено на реальному залізі: `PWMCONF` тепер зчитується з обома встановленими бітами після `setup_motors()`.

Це не впливає на розслідування sensorless homing вище (хомінг свідомо працює в spreadCycle, не stealthChop) — це покращення якості для **звичайного** руху (гойдалка/обертання), який якраз використовує stealthChop.

## Нотатки з налаштування офіційного SDK Waveshare (`STServo_Python/`)

Демо-скрипти в `STServo_Python/` прийшли від Waveshare без залежності `scservo_sdk` — вона підвантажена окремо в `scservo_sdk/` (з офіційного репозиторію `ftservo/FTServo_Python`), щоб спрацював `sys.path.append("..")` + `from scservo_sdk import *`.

Кожен скрипт захардкоджує `DEVICENAME` (за замовчуванням Windows `COM*`) — виставте фактичний пристрій, наприклад `/dev/ttyACM0` на Linux. `BAUDRATE` в `ping.py` теж був захардкоджений на `115200`, а не на заводську швидкість серії ST/STS `1000000` — виправлено в копії цього репозиторію.

`ping.py` (і інші) використовують `termios` вже на етапі імпорту для підтримки запиту "press any key", що кидає `termios.error: (25, 'Inappropriate ioctl for device')`, якщо stdin не є справжнім TTY (наприклад, запуск з неінтерактивного скрипта/CI). Запускайте інтерактивно, або через `script -qec "python3 ping.py" /dev/null` для виділення псевдотерміналу.

Для швидкої перевірки з командного рядка без запиту на натискання клавіші — `STServo_Python/simple_ping.py` та `STServo_Python/simple_rotate.py`.

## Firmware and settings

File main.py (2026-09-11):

"""Bench test: TMC2209 drivers on BTT SKR Pico, controlled from the console.

Pins/addresses below are taken directly from this board's printer.cfg.
"""

from tmc2209 import TMC2209Bus, TMC2209, ADDR_X, ADDR_Y, ADDR_Z, ADDR_E

bus = TMC2209Bus(uart_id=1, tx=8, rx=9, baudrate=40000)

motors = {
    "x": TMC2209(bus, ADDR_X, step_pin=11, dir_pin=10, en_pin=12),
    "y": TMC2209(bus, ADDR_Y, step_pin=6, dir_pin=5, en_pin=7),
    "z": TMC2209(bus, ADDR_Z, step_pin=19, dir_pin=28, en_pin=2),
    "e": TMC2209(bus, ADDR_E, step_pin=14, dir_pin=13, en_pin=15),
}

RUN_CURRENT_MA = 500  # start conservative, raise once you confirm the motor stays cool


def setup():
    for name, m in motors.items():
        m.check_connection()
        print(name, "connected, IOIN version OK")
        m.enable_uart_mode(spreadcycle=False)
        m.set_current(RUN_CURRENT_MA)
        m.set_microsteps(16)
        m.enable_driver(True)
    print("all drivers ready")


def repl():
    print("commands: <axis> <steps> [delay_us]   e.g.  x 200   or   y -400 600")
    print("          off <axis>   -  disable driver")
    while True:
        try:
            line = input("> ").strip().split()
        except (EOFError, KeyboardInterrupt):
            break
        if not line:
            continue
        if line[0] == "off" and len(line) > 1 and line[1] in motors:
            motors[line[1]].enable_driver(False)
            print(line[1], "disabled")
            continue
        if line[0] in motors and len(line) >= 2:
            axis = line[0]
            steps = int(line[1])
            delay = int(line[2]) if len(line) > 2 else 800
            motors[axis].move(steps, delay)
            print(axis, "moved", steps, "steps")
            continue
        print("unrecognised command:", line)


if __name__ == "__main__":
    setup()
    repl()

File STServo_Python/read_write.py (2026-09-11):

#!/usr/bin/env python
#
# *********     Gen Write Example      *********
#
#
# Available SC Servo model on this example : All models using Protocol SC
# This example is tested with a SC Servo(SC15/SC09), and an URT
#

import sys
import os

if os.name == 'nt':
    import msvcrt
    def getch():
        return msvcrt.getch().decode()
        
else:
    import sys, tty, termios
    fd = sys.stdin.fileno()
    old_settings = termios.tcgetattr(fd)
    def getch():
        try:
            tty.setraw(sys.stdin.fileno())
            ch = sys.stdin.read(1)
        finally:
            termios.tcsetattr(fd, termios.TCSADRAIN, old_settings)
        return ch

sys.path.append("..")
from scservo_sdk import *                      # Uses SC Servo SDK library

# Default setting
SCS_ID                      = 1                 # SC Servo ID : 1
BAUDRATE                    = 1000000           # SC Servo default baudrate : 1000000
DEVICENAME                  = '/dev/ttyACM0'    # Check which port is being used on your controller
                                                # ex) Windows: "COM1"   Linux: "/dev/ttyUSB0" Mac: "/dev/tty.usbserial-*"
SCS_MINIMUM_POSITION_VALUE  = 10          # SC Servo will rotate between this value
SCS_MAXIMUM_POSITION_VALUE  = 1000
SCS_MOVING_SPEED            = 2400        # SC Servo moving speed

index = 0
scs_goal_position = [SCS_MINIMUM_POSITION_VALUE, SCS_MAXIMUM_POSITION_VALUE]         # Goal position

# Initialize PortHandler instance
# Set the port path
# Get methods and members of PortHandlerLinux or PortHandlerWindows
portHandler = PortHandler(DEVICENAME)

# Initialize PacketHandler instance
# Get methods and members of Protocol
packetHandler = scscl(portHandler)
    
# Open port
if portHandler.openPort():
    print("Succeeded to open the port")
else:
    print("Failed to open the port")
    print("Press any key to terminate...")
    getch()
    quit()

# Set port baudrate
if portHandler.setBaudRate(BAUDRATE):
    print("Succeeded to change the baudrate")
else:
    print("Failed to change the baudrate")
    print("Press any key to terminate...")
    getch()
    quit()

while 1:
    print("Press any key to continue! (or press ESC to quit!)")
    if getch() == chr(0x1b):
        break

    # Write SC Servo goal position/moving speed/moving acc
    scs_comm_result, scs_error = packetHandler.WritePos(SCS_ID, scs_goal_position[index], 0, SCS_MOVING_SPEED)
    if scs_comm_result != COMM_SUCCESS:
        print("%s" % packetHandler.getTxRxResult(scs_comm_result))
    elif scs_error != 0:
        print("%s" % packetHandler.getRxPacketError(scs_error))

    while 1:
        # Read SC Servo present position
        scs_present_position, scs_present_speed, scs_comm_result, scs_error = packetHandler.ReadPosSpeed(SCS_ID)
        if scs_comm_result != COMM_SUCCESS:
            print(packetHandler.getTxRxResult(scs_comm_result))
        elif scs_error != 0:
            print(packetHandler.getRxPacketError(scs_error))

        # Read SC Servo moving status
        moving, scs_comm_result, scs_error = packetHandler.ReadMoving(SCS_ID)
        if scs_comm_result != COMM_SUCCESS:
            print(packetHandler.getTxRxResult(scs_comm_result))
        else:
            print("[ID:%03d] GoalPos:%d PresPos:%d PresSpd:%d" % (SCS_ID, scs_goal_position[index], scs_present_position, scs_present_speed))
        if scs_error != 0:
            print(packetHandler.getRxPacketError(scs_error))

        if moving==0:
            break

    # Change goal position
    if index == 0:
        index = 1
    else:
        index = 0

# Close port
portHandler.closePort()

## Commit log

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2026-09-11 Document ST3215 servo troubleshooting session, vendor Waveshare SDK
    The servo doesn't respond over the bus. Diagnosed step by step (jumper,
    power, wiring, MCU-side loopback, baud/ID sweep, cable swap) down to a
    hardware fault in the adapter/cable/servo chain, confirmed independently
    with the official Waveshare scservo_sdk run directly against the adapter
    over USB (bypassing the SKR Pico entirely) - same failure there too.
    Also adds AGENTS.md (generic agent-workflow notes alongside CLAUDE.md) and
    vendors scservo_sdk/ + the STServo_Python/ demo scripts (ported DEVICENAME
    to /dev/ttyACM0) used for that independent verification.
    [change_id.py, ping.py, read.py]
2026-09-11 Add simple ping/rotate scripts, fix ping.py's default baudrate
    ping.py hardcoded BAUDRATE=115200, which isn't the ST/STS-series
    factory default (1000000) and caused misleading "no status packet"
    results during bring-up. Also add simple_ping.py/simple_rotate.py:
    minimal versions of the official demo without the interactive
    "press any key" prompt, for quick command-line servo checks.
    [ping.py, simple_ping.py, simple_rotate.py]
2026-09-11 Fix st3215.py: remove bogus echo-drain that was swallowing real replies
    The real bug behind the ST3215 "no response" saga: write_register/
    read_register copied tmc2209.py's post-write echo-drain, which is only
    correct on that bus (TX wired into RX through a resistor, so every byte
    genuinely echoes). The Waveshare adapter is a real transceiver - TX/RX
    stay electrically separate on our side, so there's no echo to drain.
    The servo replies within microseconds, faster than the bogus drain's
    timeout, so that read call was swallowing the real reply every time and
    then waiting forever for a second one. Confirmed fixed end-to-end
    through the SKR Pico: ping/read_position/set_goal_deg all work now.
    Al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
    [move_test.py, ping_test.py, st3215.py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]
2026-09-11 st3215.py: add Waveshare-style verbose status API (comm result + error byte)
    Adds COMM_SUCCESS/COMM_RX_TIMEOUT/COMM_RX_CORRUPT result codes, ERRBIT_*
    servo error flags, and get_result_text()/get_error_text() message helpers,
    matching the official scservo_sdk's wording. ServoBus gains ping_status/
    read_status/write_status returning (result, error) (and data for reads);
    the existing simple ping()/read()/write() now build on top of those,
    unchanged for scanner_rig.py. ST3215 gains ping_verbose()/
    read_position_verbose()/set_goal_verbose() for the same reporting style
    at the per-servo level.
    _txrx now also actually validates the checksum and reply header instead
    of only checking length, so a co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
    [move_test.py, ping_test.py, st3215.py]
2026-09-11 Add Z axis (bounces MIN/MAX like Y), fix asyncio.sleep_us crash
    Z uses the same pins/address as the machine's old printer.cfg
    (step=IO19 dir=IO28 en=IO2, addr=1) and the same Y/Z/S console command
    shape (Z MIN/MAX/SPEED/START/STOP). Factored y_task into a shared
    bounce_task(motor, state_key) instead of duplicating it for Z.
    Also fixes a real bug found while testing this for real through the
    production asyncio.gather() path for the first time: this uasyncio
    build has no sleep_us (only sleep/sleep_ms), so x_task/bounce_task
    would raise AttributeError as soon as they actually ran - previously
    X/Y motion had only ever been verified through plain blocking
    time.sleep_us() bench scripts, never thr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
    [scanner_rig.py]
2026-09-11 X START: add optional CW/CCW direction argument, defaults to CW
    X START [CW|CCW] sets direction by flipping the sign of the stored
    speed magnitude (positive = CW), then starts. Bare X START keeps
    whatever direction was last set (CW by default, since initial state
    speed=200 is positive). print_status() now also shows X's direction.
    [scanner_rig.py]
2026-09-11 Rename servo axis command letter S -> A
    S collided with nothing functionally, but A reads better as
    "the angle/attachment axis" alongside X/Y/Z. Renamed throughout:
    docstring, state["a"], command dispatch, print_status.
    [scanner_rig.py]
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2026-09-11 Add TMC2209 sensorless homing (StallGuard) as Y/Z endstop replacement
    tmc2209.py: enable_stallguard(sgthrs, tcoolthrs) configures TCOOLTHRS/
    SGTHRS on the driver; read_stallguard_result() reads live SG_RESULT;
    is_stalled(sgthrs) does the software-side threshold comparison (kept
    separate from the on-chip SGTHRS register so the threshold can be
    retuned live via the console without rewriting driver registers).
    scanner_rig.py: Y/Z gain a persisted "sgthrs" field and a new
    "Y SGTHRS <n>" / "Z SGTHRS <n>" command. bounce_task polls
    is_stalled() every STALL_CHECK_EVERY_N_STEPS steps once
    STALL_SETTLE_STEPS have passed since the last reversal (SG_RESULT
    reads ~0 - not "stalled", just not-yet-valid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
    [scanner_rig.py, tmc2209.py]
2026-09-11 Add top-level START/STOP: run all axes as one timed cycle
    START [minutes] flips running=True on X/Y/Z/A at once, using whatever
    SPEED/MIN/MAX/SGTHRS/etc each already has configured, and schedules
    an auto-stop after the given duration (default 5 min). A bare STOP
    halts everything immediately. Re-issuing START cancels the previous
    cycle's pending auto-stop timer instead of leaving it dangling.
    [scanner_rig.py]
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2026-09-11 Add Y/Z HOME command: deliberate StallGuard homing with direction/speed
    "Y HOME [DEC|INC] [speed]" / "Z HOME [DEC|INC] [speed]" drives toward
    one end (Y defaults to DEC, Z to INC, both at 150 steps/sec - gentler
    than the normal bounce SPEED default) until StallGuard trips, then
    sets MIN (DEC) or MAX (INC) to the actual stall position. Direction/
    speed passed as arguments are remembered as the new default for next
    time. Meant as an explicit one-shot calibration before the first
    START, using the same settle-then-poll StallGuard logic as bounce_task.
    home_dir/home_speed are now persisted alongside the existing Y/Z
    fields. load_config() also now backfills and saves any field missing
    from an exi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
    [scanner_rig.py]
2026-09-11 Fix HELP command crash: __doc__ is unset when run directly via Thonny
    MicroPython doesn't populate __doc__ for the top-level script when run
    directly (e.g. Thonny's Run button), only for imported modules -
    handle_command's HELP branch called print(__doc__), which raised
    NameError as soon as anyone typed HELP in that context. Moved the
    docstring text into an explicit HELP_TEXT module variable instead, so
    it's always defined regardless of how the file is executed.
    [scanner_rig.py]
2026-09-11 Make handle_command crash-proof: catch any exception, never propagate
    Any unhandled exception inside command handling used to propagate up
    through console_task and kill the whole asyncio.gather() in main() -
    one bad command (or an unforeseen bug, like the recent __doc__ one)
    would take down X/Y/Z/servo motion along with the console, not just
    fail that one command.
    Renamed the existing body to _dispatch_command and made handle_command
    a thin wrapper that catches Exception and reports it to the console
    ("? command failed (<type>): <msg> - <line>") instead of raising.
    Verified with unrecognised commands, bad numeric values, and a forced
    arbitrary exception (ZeroDivisionError) - all reported wi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
    [scanner_rig.py]
2026-09-11 Fix several real bugs in Y/Z sensorless homing, still tuning threshold
    Fixes found while chasing "DIAG never trips" across a huge parameter
    sweep, all confirmed against real reference implementations:
    - TCOOLTHRS direction was backwards (was set low thinking that enables
    StallGuard at low speed; the datasheet's "lower threshold velocity
    for switching ON" means the opposite - it's a MINIMUM speed, active
    above it). Reverted to the register max (0xFFFFF) = active at any
    practical speed. Confirmed against Chr157i4n/PyTmcStepper.
    - Homing now runs at HOME_CURRENT_MA (reduced from the normal run
    current) and forces spreadCycle, both restored via try/finally -
    matches the Voron sensor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
    [scanner_rig.py]
2026-09-12 tmc2209.py: enable pwm_autoscale/pwm_autograd in PWMCONF for stealthChop
    enable_uart_mode() configured GCONF and set_current() configured
    IHOLD_IRUN correctly, but PWMCONF (0x70) was never touched - without
    pwm_autoscale (bit 18) and pwm_autograd (bit 19), stealthChop's
    current-regulation loop can't adapt to the actual motor/load and runs
    open-loop off reset defaults, which is rougher/louder than intended.
    Fixed via a read-modify-write so the factory pwm_freq/pwm_grad/pwm_ofs
    are left alone. Confirmed on real hardware: PWMCONF reads back with
    both bits set after setup_motors(). Doesn't affect the sensorless-
    homing work (that deliberately uses spreadCycle) - this is purely a
    quality improvem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
    [tmc2209.py]
2026-09-12 Adopt SGTHRS=100/1kHz defaults from a confirmed-working hand-stall prototype
    Adds google_test_stall_guard.py, a separate MicroPython prototype
    targeting the same Y driver/pins, reported to successfully detect a
    hand-applied stall using SGTHRS=100, a 1kHz step rate, and a moderate
    IRUN=14 current chosen to be spinnable-but-hand-stoppable.
    Its GCONF=0x1C sets the same bit this codebase calls en_spreadcycle to
    1, commented there as "StealthChop2" - per our own measured noise data
    (0-24 under stealthChop vs 0-4 under spreadCycle), bit=1 is actually
    spreadCycle, so that script's success is consistent with our earlier
    finding rather than contradicting it; the comment there is just
    mislabeled. (It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
    [google_test_stall_guard.py, scanner_rig.py]
2026-09-12 Y/Z sensorless homing: poll SG_RESULT over UART instead of DIAG pin
    DIAG-pin-based stall detection in bounce_task/home_axis never tripped
    reliably on real hardware. A confirmed-working reference script
    (google_test_stall_guard.py, committed earlier) detects stalls purely
    by polling the TMC2209's SG_RESULT register over UART and comparing
    it to a plain threshold - no DIAG pin involved. home_axis is rewritten
    to do the same (~100ms poll cadence), with a linear speed ramp-up
    (avoids false trips from the motor missing steps right off a stop) and
    a corrected HOME_CURRENT_MA (830mA, matching the reference's IRUN=14 -
    the previous 400mA computed out to a much weaker CS~6).
    bounce_task drops live S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
    [scanner_rig.py, tmc2209.py]
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2026-09-13 Add MOVE commands: mm-based positioning for Y/Z, degrees for X/A
    Y/Z MOVE takes a relative distance in millimeters, converted to steps
    via a new per-axis LEAD (lead screw pitch, mm/revolution, persisted -
    default 4mm) and a fixed 3200 microsteps/rev (200 full steps x 16
    microsteps, matching setup_motors()). Clamped to MIN/MAX so it can't
    grind past a homed limit.
    X MOVE takes a relative angle in degrees instead, since X turns the
    turntable directly rather than driving a screw - same step-count
    conversion, no screw/lead involved. X has no MIN/MAX (continuous
    rotation, no fixed reference) so it isn't clamped.
    A MOVE also takes a relative angle in degrees, but unlike the open-loop
    stepper axe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
    [scanner_rig.py]
2026-09-13 Track and persist current position for X/Y/Z, show it in STATUS
    X/Y/Z have no position sensor - "pos" was already an open-loop step
    counter for Y/Z (used for bouncing/MOVE), but it reset to 0 on every
    reboot since it wasn't persisted, and X didn't track it at all. Both
    are fixed: X now tracks pos the same way Y/Z do, and all three persist
    it to rig_config.json.
    Position isn't saved on every step (would hammer the flash and add
    latency to the step loop) - instead a new position_autosave_task
    checkpoints it every 10s while it's actually changing, and STOP
    (individual or all-axes) checkpoints it immediately for the common
    "pausing deliberately" case.
    A (the ST3215 servo) doesn't need any of t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
    [scanner_rig.py]
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2026-09-13 Add ZERO command and make HOME zero position at the stall point
    HOME previously set MIN (DEC) or MAX (INC) to whatever the raw pos
    counter happened to read at the stall, leaving pos itself at an
    arbitrary accumulated value. It now zeroes pos at the stall point
    instead - the homed-toward limit ends up exactly 0, and the other
    limit shifts by the same offset so it keeps meaning the same real
    distance from the new origin. Factored into a shared zero_position()
    helper.
    Also exposes that same zeroing as a standalone X/Y/Z ZERO command, for
    redefining the origin by hand wherever the axis currently is - no
    motion, no StallGuard. X has no HOME at all (continuous rotation,
    nothing to stall against),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
    [scanner_rig.py]
2026-09-13 Add X/Y/Z TMC command: TMC2209 driver health status
    Decodes GSTAT and DRV_STATUS per the official TMC2209 datasheet (rev
    1.03, section 5.5.3 for DRV_STATUS; GSTAT bits from the general config
    register table) into a one-line summary: OK, or ERROR(...) listing any
    of RESET/DRV_ERR/UV_CP (GSTAT) or
    OTPW/OT/S2GA/S2GB/S2VSA/S2VSB/OLA/OLB (DRV_STATUS), plus cs_actual (the
    driver's live current scale), mode (stealthChop/spreadCycle), and
    standstill.
    GSTAT is a write-clear register - it's cleared after each read so a
    one-time RESET event (expected right after power-up) doesn't keep
    showing as if it just happened on every later check.
    New tmc2209.py methods: read_gstat, clear_gstat, read_drv_status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
    [scanner_rig.py, tmc2209.py]
2026-09-13 Add A TMC command: ST3215 servo health status
    Mirrors X/Y/Z TMC's diagnostic summary but for the servo: reads
    voltage, temperature, load, and current (registers verified against
    the vendored official SDK, scservo_sdk/sms_sts.py - addr 60/62/63/69,
    scaling from the Feetech SMS/STS register table: voltage x0.1V,
    current x6.5mA, temperature raw C, load = 10-bit magnitude + direction
    bit, left unscaled since the percentage isn't independently
    confirmed), plus the protocol status/error byte every reply carries,
    decoded into the same OK/ERROR(...) format as the TMC2209 command
    (VOLTAGE/ANGLE/OVERHEAT/OVERELE/OVERLOAD).
    New st3215.py methods: read_voltage, read_temperature, read_load,
    read_current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
    [scanner_rig.py, st3215.py]
2026-09-13 X/Y/Z TMC: show live current in mA, microsteps, and configured SGTHRS
    current_ma replaces the raw CS_ACTUAL scale with milliamps, via a new
    cs_to_ma() (inverse of the existing set_current() formula, using the
    driver's own rsense/vsense). microsteps is read back live from CHOPCONF
    (R+W, unlike IHOLD_IRUN/TCOOLTHRS/SGTHRS) via a new read_microsteps(),
    instead of just trusting whatever set_microsteps() was last called
    with.
    SGTHRS can't be read back at all - it's write-only on this chip (see
    the existing enable_stallguard note) - so diag_summary() takes it as an
    optional parameter and echoes it back labeled "(cfg)" to make clear
    it's the last value scanner_rig.py's own state configured, not a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
    [scanner_rig.py, tmc2209.py]
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2026-09-13 Add X/Y/Z MICROSTEPS and CURRENT commands, make both per-axis config
    Microsteps and run current were previously fixed, shared constants
    (MICROSTEPS, X/Y/Z_CURRENT_MA) applied once in setup_motors(). Both are
    now per-axis state, persisted, and changeable live via new "X/Y/Z
    MICROSTEPS <n>" and "X/Y/Z CURRENT <mA>" commands.
    MICROSTEPS is the more delicate one: one step means a different real
    distance at a different microstep setting, so changing it rescales
    pos/MIN/MAX by the resolution ratio (new set_axis_microsteps()) - the
    same reasoning as zero_position()'s coordinate shift - so an existing
    HOME calibration keeps meaning the same physical location instead of
    silently going wrong. The dri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
    [scanner_rig.py]
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2026-09-13 MIN/MAX/SPEED/SGTHRS/MICROSTEPS/CURRENT with no value queries it
    "Y MIN" (2 words, no value) now prints Y's current min instead of
    falling through to "? unrecognised command". Implemented as a small
    _QUERYABLE_FIELDS map (sub-command -> {axis: state field}) checked
    right after axis/sub are parsed, before the existing set-value
    if/elif chain - so a bare query short-circuits cleanly without
    touching persist/save logic, and an axis/field combo that doesn't
    exist (e.g. "X SGTHRS", "A MICROSTEPS") still correctly falls through
    to "unrecognised command" instead of being silently misreported.
    START/STOP/ZERO/TMC/HOME/MOVE/LEAD are deliberately not in the map -
    they're actions, not value settings,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
    [scanner_rig.py]
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2026-09-13 Unify X with Y/Z/A: give it MIN/MAX (degrees) and MOVE clamping/pseudo-positions
    X previously had no MIN/MAX at all ("continuous rotation, no fixed
    reference"), so its MOVE was unclamped and didn't support the
    MIN/MAX/MID pseudo-positions the other three axes just got. For
    unification, X now has its own min_deg/max_deg (default 0/180, so MID
    = 90) via new "X MIN <deg>"/"X MAX <deg>" commands (merged into the
    existing A MIN/MAX dispatch branches, since the logic and units are
    identical).
    X's bounds are kept in degrees (min_deg/max_deg, like A) rather than
    steps (like Y/Z's min/max) - X's natural unit is angular (MOVE already
    took degrees for it), and degrees are resolution-independent, so a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
    [scanner_rig.py]
2026-09-13 Make plain numeric X MOVE unbounded again (MIN/MAX only for pseudo-positions)
    The previous unification commit clamped X MOVE's numeric-degree form
    to MIN_DEG/MAX_DEG same as Y/Z's MOVE clamps to MIN/MAX - but X is
    continuous rotation, and multi-revolution moves ("X MOVE 720" for two
    full turns) are a legitimate use case that clamping breaks. Reverts
    rotate_x() to move exactly the given degrees with no clamp, same as
    before the unification work; MIN_DEG/MAX_DEG (and the MIN/MAX/MID
    pseudo-positions in rotate_x_to()) are unaffected and still work as
    added.
    Verified on real hardware: "X MOVE 720" moved exactly 6400 steps (two
    full turns at 3200 steps/rev) despite max_deg=180, and "X MOVE -720"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
    [scanner_rig.py]
2026-09-13 Add SLEEP/WAKE: idle power-down with servo-sag recovery
    SLEEP stops every axis, disables the X/Y/Z TMC2209 drivers outright
    (EN pin - no holding current at all, unlike just standing still with
    IHOLD applied) and releases the ST3215's torque, to cut power/heat
    during long idle stretches. Triggers either by typing SLEEP directly,
    or automatically after SLEEP_TIMEOUT_S (20 minutes) of no console
    input with nothing running - a new sleep_monitor_task checks this
    every SLEEP_CHECK_INTERVAL_S and only fires when no axis is actually
    moving, however stale the last-activity timestamp is.
    Because a torque-less servo can sag under whatever weight it's
    holding, enter_sleep() records the servo's angle ri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
    [scanner_rig.py]
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2026-09-13 Y/Z MIN/MAX: millimeters instead of raw steps, with config migration
    Y/Z's MIN/MAX were the last thing still expressed in raw steps -
    MOVE already worked in mm via LEAD, and X's MIN/MAX (added earlier)
    are in degrees, not steps. Renamed to MIN_MM/MAX_MM and converted the
    same way MOVE already does (steps_per_rev(axis)/lead_mm), for the same
    reason X's bounds are in degrees: millimeters are a physical,
    resolution-independent unit, so - like X's MIN_DEG/MAX_DEG - a
    MICROSTEPS change no longer needs to rescale them at all (only "pos"
    itself does; set_axis_microsteps's old min/max-in-steps rescale
    branches are gone, dead code now that no axis keeps bounds in steps).
    load_config() gained a one-t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
    [scanner_rig.py]
2026-09-13 Pretty-print rig_config.json for easier manual inspection/editing
    MicroPython's json.dumps has no indent= option (unlike CPython's), so
    plain json.dump() always produced one dense, hard-to-scan line. Adds a
    small hand-rolled _pretty_json() that indents the two levels this
    config actually has (axis -> flat field:value dict), using json.dumps
    per key/value so strings/floats/bools/None still get correctly
    escaped/formatted. Purely a save-side formatting change - load_config()
    still just json.load()s the file, which doesn't care about whitespace.
    Verified on real hardware: the written file is now indented and
    readable, and every persisted field round-trips through json.load()
    back to the exact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
    [scanner_rig.py]
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2026-09-13 Y/Z LEAD with no value queries it, like MIN/MAX/SPEED/etc already do
    "Y LEAD" (no value) was falling through to "? unrecognised command" -
    LEAD was left out of _QUERYABLE_FIELDS when that mechanism was added.
    Added {"Y": "lead_mm", "Z": "lead_mm"} alongside the other queryable
    fields; X has no LEAD (not a screw-driven axis), so "X LEAD" still
    correctly falls through to "unrecognised command" rather than crashing
    or misreporting.
    Verified on real hardware: "Y LEAD"/"Z LEAD" print the current value
    (4.0), "X LEAD" is rejected cleanly.
    [scanner_rig.py]
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2026-09-13 Fix STOP not interrupting an in-progress MOVE/HOME
    Reported as "Y MOVE -30" followed by "Y STOP" not stopping anything.
    MOVE/HOME run as one-shot asyncio tasks that step straight through to
    completion once started - they never checked state[key]["running"]
    during their loop (that flag belongs to bounce_task/x_task/servo_task's
    continuous cycling, which MOVE/HOME deliberately runs instead of, per
    their own docstrings). STOP only ever touched that flag, so it had
    nothing to actually interrupt an active MOVE/HOME with.
    Adds _move_tasks (X/Y/Z), tracking the current one-shot task per axis,
    and _cancel_move_task() to actually cancel it. Both the per-axis STOP
    branch and stop_all() now call this.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
    [scanner_rig.py]
2026-09-13 Make device init crash-proof: no hard boot failures, OFFLINE status, auto-retry
    setup_motors() called TMC2209.check_connection() unguarded, so a driver
    that doesn't respond at boot (not wired up yet, still powering on,
    etc.) raised OSError straight out of setup_motors() and crashed the
    whole program before the console or any other axis ever came up -
    reported as "перше немає зв'язку з tmc2209, від чого програма зразу
    падає жорстко."
    Adds device_online (x/y/z/a) tracking, and _init_stepper()/_init_servo()
    that wrap each device's init in its own error handling instead of
    letting one bad device take down the others:
    - check_connection() gets 3 q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
    [scanner_rig.py]
2026-09-13 Fix motion stutter from position autosave: 10s -> 10min, checkpoint on SLEEP
    Reported as a fraction-of-a-second hang during Y movement. Measured
    save_config() on real hardware: 50-112ms per call, blocking the whole
    event loop (MicroPython's flash writes are synchronous, so uasyncio
    can't run anything else - including step timing - until it returns).
    At the old POSITION_AUTOSAVE_INTERVAL_S=10s, that's a felt stutter
    roughly every 10 seconds of continuous motion.
    Raises the interval to 10 minutes, trading a bigger power-loss window
    for making the blocking write ~60x rarer. To compensate, enter_sleep()
    now checkpoints X/Y/Z's pos immediately (same as STOP already did) -
    SLEEP (manual or the id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
    [scanner_rig.py]
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
